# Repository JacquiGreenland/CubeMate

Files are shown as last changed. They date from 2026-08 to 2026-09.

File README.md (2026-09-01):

# CubeMateEQ

> **Compact open-source strain-wave drive telescope mount for luggable (portable) astrophotography and visual astronomy**

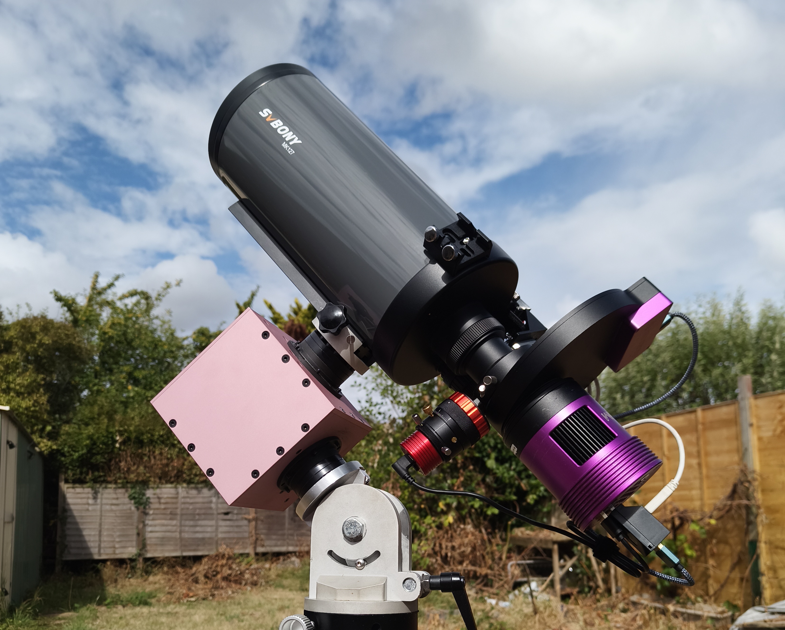
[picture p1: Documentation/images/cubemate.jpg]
CubeMateEQ


CubeMateEQ is a compact, open-source telescope mount designed around low-cost strain-wave (harmonic) gearboxes, stepper motors, CNC-machined aluminium parts, and the [OnStepX](https://github.com/hjd1964/OnStepX) control platform.

The project was created because I wanted to build my own mount based around strain-wave gearboxes and evolved into an exploration of how far a practical DIY strain-wave mount could be taken using off-the-shelf parts. The result is a vaguely travel-friendly, modular, and compact mount that can be assembled with basic tools. It can operate in either **Equatorial (EQ)** or **Alt-Az** configurations and has been validated with real astrophotography workloads, including guiding at approximately 1 metre focal length while carrying a 6 kg payload.

CubeMateEQ is intended as an **open hardware engineering project**, not a commercial product. It is buildable, modifiable, and intended to be improved by the community.

---

## Project status

CubeMateEQ is currently at a **field-validated prototype / open-hardware release** stage.

The current design has:

- been fully assembled in CNC-machined aluminium;
- been tested in both lightweight and higher-load configurations;
- demonstrated sustained guided astrophotography at approximately 975 mm focal length;
- demonstrated sub-arcsecond guiding for sustained periods;
- successfully produced long guided exposures (10 min) without meaningful exposure-time-dependent star elongation;
- been tested with OnStepX using an ESP32-S3-based controller on a custom PCB;
- been prepared for travel use as a practical hold-luggage astrophotography mount for heavier payloads.

The design is functionally complete, although there are still areas of refinement and experimentation, particularly around firmware behaviour, slew microstepping, mount limits, and future mechanical improvements.

---

## Why CubeMateEQ?

Commercial compact strain-wave drive mounts are excellent, but they were also extremely expensive when this project started. In recent years cheaper options using a similar mechanical principle to CubeMateEQ have appeared, but the major commercial brands still typically involve spending several times the parts cost of assembling CubeMateEQ.

CubeMateEQ was designed around my personal priorities:

- **open mechanical and electronic design;**
- **commodity strain-wave drives and motors;**
- **repairability and replaceable controller hardware;**
- **luggable form factor;**
- **real astrophotography performance rather than theoretical payload claims;**
- **modularity and scope for future upgrades.**

The aim is not to claim that CubeMateEQ is a drop-in replacement for every commercial strain-wave mount. Commercial products offer advantages such as factory QA, tested periodic-error characteristics, support, warranties, and polished integration.  Some manufacturers, such as MLAstro, offer similar repairability along with all the other commercial benefits of precision and support.

CubeMateEQ instead demonstrates what can be achieved with open hardware, relatively inexpensive components, careful mechanical design, and community software. It is not unique in this, but the design is highly modular and can be extended around the same basic form factor and principle.

---

## Why 'Luggable' and not 'Portable'

CubeMateEQ is notionally portable, and my wife and I certainly will be travelling with it, but it is not something you can simply throw into your hand luggage. It's the same size and weight as many commercial strain-wave mounts and it bothers me that they refer to them as portable!  The term is a deliberate nod to the old Compaq "luggables": portable PCs, certainly, but a long way from what laptops would eventually become.

---

## Why the name CubeMateEQ?

During development I used AI extensively to check calculations, analyse guiding logs, and accelerate a variety of supporting tasks so that I could spend more time on the engineering decisions themselves. At one point, somewhat randomly, the AI referred to the project as "CubeMateEQ". I liked the name enough that it stuck.

---

## Key features

- Compact CNC-machined aluminium construction
- Strain-wave drive RA and DEC axes
- Belt reduction between stepper motor and strain-wave gearbox
- Equatorial and Alt-Az operation
- Inexpensive ESP32-S3 controller
- OnStepX-compatible control electronics
- Open mechanical design
- Open PCB and wiring documentation
- Modular axis and mounting interfaces
- Designed for luggable astrophotography
- Proven with guided imaging at approximately 975 mm focal length
- Designed to be serviceable and reproducible using readily obtainable parts

---

## Mechanical architecture

The current CubeMateEQ prototype uses:

- **Type 14 cup-style strain-wave drives**
- **100:1 primary reduction**
- **NEMA 17 stepper motors**
- **GT2 belt reduction**
- **16-tooth motor pulley**
- **80-tooth driven pulley**
- **5:1 belt reduction**
- **500:1 total reduction**

The structure is CNC-machined aluminium and is designed around a compact cube-like form factor using a fully enclosed torsion-box structure for stiffness.

The current luggable configuration is intended for imaging payloads in the approximate **5–10 kg class**, with higher loads possible depending on balance, counterweight use, strain-wave drive selection, tripod/pier stiffness, and imaging requirements.

Larger strain-wave drives and stronger motors remain possible future development paths.

---

## Electronics and control

CubeMateEQ uses a custom controller PCB designed around a **Waveshare ESP32-S3 Zero** and TMC2209 stepper drivers.

The mount runs **OnStepX**, which provides:

- telescope mount control;
- sidereal tracking;
- GOTO operation;
- guiding support;
- EQ and Alt-Az mount modes;
- meridian and limit handling;
- INDI / application integration.

OnStepX needs to be downloaded separately and compiled with the supplied pinmap and configuration files along with any other desired software changes.

The repository includes CubeMateEQ-specific configuration material and the custom ESP32-S3 pin map required for the controller PCB.

> **Important:** always verify the supplied pin map against the PCB revision being built. Step/direction assignments and TMC UART addressing must agree with the physical board.

---

## Proven astrophotography performance

CubeMateEQ has been tested using several imaging configurations.  All of these tests were performed in suburban Bristol and not under pristine dark skies.

### ~180 mm imaging

With a lightweight imaging payload consisting of a ZWO ASI585MC Air and a Nikon 180 mm prime lens, using the custom wedge and an EQ5 tripod, CubeMateEQ has demonstrated sustained sub-arcsecond guiding.

### ~975 mm imaging

The mount was also tested with a substantially more demanding imaging train consisting of an SVBONY MK127 using its supplied focal reducer giving approximately **975 mm focal length** paired with an Altair filter wheel, an Altair 585MM camera, and a ZWO off-axis guider with a QHY5L-II-M guide camera, along with a stepper motor, bracket, and a DIY Moonlite-compatible focuser, in conjunction with the custom wedge and an EQ5 tripod.  This payload is approximately 6 kg in total - a 1.9 kg counterweight was used.

Representative results with this payload included:

- mature guiding around **1.2–1.4 arcsec RMS** near the celestial equator;
  - approximately **0.88 arcsec RMS** during a 240-second exposure;
  - approximately **1.15 arcsec RMS** during a 300-second exposure;

- sustained sub-arcsecond intervals imaging a more favourable high-declination target (C4);
  - approximately **0.59 arcsec RMS** during a 300-second exposure;
  - approximately **0.85 arcsec RMS** during a 600-second exposure.

Matched-star analysis showed no meaningful increase, or variation, in star elongation across exposure durations from 1 to 10 minutes.

These results are included as engineering validation rather than guaranteed performance. Guiding performance depends heavily on seeing, payload, balance, polar alignment, guiding configuration, optical geometry, tripod stiffness, wind, and individual strain-wave drive characteristics.

---

## Periodic error and guiding

As expected for an inexpensive commodity strain-wave gearbox, the RA axis exhibits periodic error.

Testing has shown a strong repeatable periodic component of approximately **428–431 seconds** in the Type 14 gearbox currently installed on the RA axis.

PHD2 Predictive PEC (PPEC) materially improves RA guiding once the period is learned.

Different gearboxes will almost certainly exhibit different periodic error. Because CubeMateEQ is designed around off-the-shelf components this variability is treated as something to accommodate through guiding rather than eliminate through individual selection of expensive high-precision components.

---

## Payload

CubeMateEQ does not use a single absolute payload rating because useful payload depends on the application, counterweights, distance of the payload from the centre of rotation, and many other factors.

As a practical guide:

- **5–6 kg without counterweight** is a realistic upper limit for luggable-use;
- around **10 kg** is a sensible design target for the current luggable configuration with appropriate counterweights;
- larger loads may be possible with a combination of counterweighting and careful setup;
- future Type 17 or larger strain-wave-drive variants could increase the available torque substantially.

For astrophotography, guiding performance is a more useful measure than whether the mount can simply carry a given mass.

---

## Counterweights

Like many strain-wave-drive mounts, CubeMateEQ can be used without a counterweight for lighter payloads.

Counterweights can still be useful because they:

- reduce static loading on the RA strain-wave drive;
- reduce tripod overturning moment;
- improve stability with longer or heavier optical systems;
- increase the usable payload range.

The current design supports counterweight use where required using a counterweight shaft with a 12 mm thread. This allows several different off-the-shelf counterweight systems to be used.  The reference model uses a ZWO counterweight shaft with a 12 mm thread and a 20 mm diameter and SkyWatcher EQ5 weights.

---

## Equatorial mounting

CubeMateEQ can be configured for equatorial use.

The current prototype uses a **custom EQ wedge**. That wedge is not included in the initial open release because the present design is functional but not sufficiently user-friendly to be recommended as a general solution.

Instead, the repository includes a step file for a Vixen-Style Dovetail plate that allows CubeMateEQ to be attached to other EQ wedge solutions.

A more refined open EQ wedge is planned for the future.

---

## Alt-Az operation

CubeMateEQ can also be operated as an Alt-Az mount through OnStepX.

This makes it suitable for:

- visual astronomy;
- planetary imaging;
- solar and lunar work;
- short-exposure imaging;
- applications where field rotation is acceptable or compensated elsewhere.

---

## Build cost

The current reference model was built for approximately **USD $500** although prices have risen a little since then and I would expect to pay around **USD $600** at current pricing.

This figure is indicative only and excludes:

- tripod / pier / wedge;
- variations in local pricing.
- shipping costs;
- import taxes;

At the time of writing the CNC aluminium parts and the PCB for the reference model cost approximately **USD $240**. The Type 14 strain-wave gearboxes can be sourced for as little as **USD $100 each** from Aliexpress. The stepper motors are sourced from StepperOnline for **USD $14 each**.  Ancillary parts, including the electronics, can be sourced from amazon for These two expenditures account for the bulk of the build cost, most of the rest of the items can be sourced from Amazon for about **USD $100** total.

Repeat builds may vary significantly depending on supplier and location. Supply chain status and availability of materials will also impact spot pricing.

---

## Repository contents

The repository is divided into the following functional directories:

```text
/
├── README.md
├── LICENSES.md
├── hardware/
│ ├── Mechanical/
│ └── PCB/
├── firmware/
│ ├── Config.h
│ ├── Extended.config.h
│ └── Pins.MaxESP4.h
└── Documentation/
```

The repository includes:

- mechanical STEP files;
- manufacturing drawings;
- PCB design files;
- controller pin mapping;
- CubeMateEQ-specific OnStepX configuration;
- Bill of Materials;
- assembly documentation.

---

## Assembly

Detailed assembly instructions are provided separately in the documentation.

The high-level build sequence is:

1. Assemble the strain-wave-drive axis structures.
2. Fit shafts, bearings, pulleys, and belts.
3. Install the stepper motors.
4. Assemble the RA and DEC structures.
5. Install the controller electronics.
6. Connect the stepper drivers and motors.
7. Attach the payload mounting interface.
8. Install the mount onto the chosen EQ wedge, pier, tripod, or Alt-Az base.
9. Flash and configure OnStepX.
10. Verify axis direction, travel limits, current settings, and motor mapping before mounting valuable equipment.

---

## Firmware

CubeMateEQ uses [OnStepX](https://github.com/hjd1964/OnStepX).

OnStepX is a separate project and remains subject to its own licence.

CubeMateEQ-specific configuration files are supplied only to make it easier to reproduce the tested hardware configuration.

Builders should retain a known-good firmware image before experimenting with settings such as:

- tracking microsteps;
- slew microsteps;
- motor current;
- Axis-1 limits;
- meridian behaviour;
- limit recovery;
- guide rate;
- mount startup behaviour.

---

## Safety

CubeMateEQ is an experimental open-hardware telescope mount.

A telescope mount is capable of producing substantial torque and can damage equipment, trap fingers, wrap cables, or drive an optical system into a tripod or pier if incorrectly configured.

Builders are responsible for validating:

- axis directions;
- software limits;
- physical clearances;
- cable routing;
- current limits;
- power supply;
- motor temperature;
- balance;
- mount stability.

Always test motion without valuable optics attached when commissioning a new build or firmware configuration.

---

## Licensing

CubeMateEQ uses separate licences for hardware and documentation.

### Hardware

Unless otherwise stated, CubeMateEQ hardware design files are licensed under:

**CERN Open Hardware Licence Version 2 — Strongly Reciprocal (CERN-OHL-S-2.0)**

This includes relevant:

- PCB design files;
- schematics;
- mechanical CAD;
- STEP files;
- manufacturing drawings;
- hardware assemblies.

### Documentation

Documentation is licensed under:

**Creative Commons Attribution-ShareAlike 4.0 International (CC BY-SA 4.0)**

### Software

CubeMateEQ does not redistribute OnStepX.

OnStepX and other third-party software remain under their respective licences.

### Name and branding

The **CubeMateEQ** name, logo, and project branding are not licensed under CERN-OHL-S-2.0 or CC BY-SA 4.0.

Use of the open hardware does not imply that a derived product is manufactured, certified, endorsed, or supported by the CubeMateEQ project.

See `LICENSES.md` for full details and the individual `LICENSE` file in each directory for the full text of the applicable licence.

---

## Contributing

Contributions, testing results, documentation improvements, and hardware refinements are welcome.

Particularly useful contributions include:

- build reports;
- alternative CNC / manufacturing approaches;
- verified component substitutions;
- guiding performance data;
- alternative EQ wedge designs;
- controller improvements;
- mechanical tolerance feedback;
- firmware configuration findings.

When submitting performance results, please include enough information to make the data useful, such as focal length, payload, guide configuration, exposure duration, seeing conditions where known, and firmware/configuration details.

---

## Project philosophy

CubeMateEQ exists because a telescope mount does not have to be a sealed proprietary appliance.

The project is intended to remain:

- understandable;
- repairable;
- reproducible;
- modifiable;
- experimentally useful.

Commercial manufacture, group buys, assembled boards, and paid build services are compatible with the project licence, provided the obligations of the CERN-OHL-S-2.0 licence are respected for covered hardware derivatives.

---

## Acknowledgements

CubeMateEQ would not exist without the work of the OnStep / OnStepX community and the wider open-source astronomy ecosystem.

Particular thanks go to the developers and contributors behind:

- [OnStepX](https://github.com/hjd1964/OnStepX)
- [PHD2](https://openphdguiding.org/)
- [INDI](https://indilib.org/)
- [KStars](https://kstars.kde.org/)

and to everyone who has documented, tested, and shared practical experience with DIY telescope mounts and harmonic-drive systems.

---

## Disclaimer

CubeMateEQ is provided as open hardware without warranty.

Build and use it at your own risk.

Astronomy equipment can be expensive. Verify every axis, limit, connector, voltage, current setting, and firmware configuration before connecting valuable equipment.

---

**CubeMateEQ — compact, open, repairable, and extendable hardware for astronomy.**

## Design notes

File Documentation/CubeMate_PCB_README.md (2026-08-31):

# CubeMate Controller PCB

## About this board

The CubeMate controller PCB is a custom two-axis controller designed specifically for CubeMate. It provides the electronics required to drive the right ascension (RA) and declination (DEC) axes using OnStepX, while keeping the controller simple, modular and easy to repair or replace.

The design is intentionally based around readily available modules rather than permanently soldered controller or driver ICs. In the reference build, the ESP32-S3 and both TMC2209 stepper drivers are socketed so that any of them can be replaced without removing the complete PCB from service.

The board can be assembled with surface-mount parts, but through-hole alternatives are provided for the resistor and capacitors so that a fully hand-soldered build is also possible. This guide assumes that the builder is already comfortable with basic electronic assembly, component polarity, continuity checking and soldering.

This document covers the controller PCB itself. Mechanical installation of the completed PCB into CubeMate is covered by the main CubeMate assembly guide.

## Main components

A complete controller uses:

| Component | Qty | Notes | Link| 
| --- | ---: | --- | --- |
| Waveshare ESP32-S3 Zero | 1 | Main OnStep controller. Some suppliers also describe this small-format board as an ESP32-S3 Mini. | https://www.aliexpress.com/item/1005009067129211.html |
| TMC2209 V3.0 stepper driver module | 2 | One driver for RA and one for DEC. Socketing is recommended. | https://www.aliexpress.com/item/1005010256315174.html |
| 100 uF, 35 V electrolytic capacitor | 2 | One on the motor-power supply line for each TMC2209. SMD footprint plus through-hole alternative pads are provided. |  |
| Mini 360 buck converter module | 1 | Regulates the incoming supply to 3.3 V for the ESP32-S3 and TMC2209 logic. | https://www.aliexpress.com/item/1005008498997638.html |
| 1 kohm resistor | 1 | Part of the shared single-wire TMC2209 UART interface. SMD footprint plus through-hole alternative pads are provided. | |
| JST-XH 4-pin board connector | 2 | One stepper-motor connector per axis. | |
| Status LED | 1 | OnStep status indication. Mounted on the underside of the PCB. | |
| 2 x 4 GPIO header | 1 | Exposes four otherwise-unused ESP32 GPIO connections for future expansion with individual ground pins. | |
| 5.5 x 2.1 mm horizontal PCB DC jack | 1 (optional) | Centre-positive in the reference build. Direct-wired power can be used instead. | |
| USB-to-TTL serial module | 1  | Reference build uses a ZY-CP2102 module. The PCB can also accommodate a CH340E-based module. | https://www.aliexpress.com/item/1005010271946733.html |
| Pin headers / sockets | As required | Used for replaceable modules and detachable panel wiring. | |

Exact supplier links can be added to this document where useful.

## Board orientation

Almost all components are fitted to the **top/component side of the PCB**, which is the side **without the CubeMate logo**. This includes:

- the ESP32-S3 Zero;
- both TMC2209 drivers;
- the Mini 360 buck converter;
- the two 100 uF capacitors;
- the 1 kohm UART resistor;
- the JST-XH motor connectors;
- the optional serial module;
- the power connector or power wiring;
- the expansion headers.

The **status LED is the exception**. It is mounted on the **underside/logo side** of the PCB.

When the completed board is installed in CubeMate, the populated side faces down into the enclosure and the underside faces the top cover. A small hole in the top cover allows the status LED to be seen without exposing the observer to a bright direct LED.

## Power input

The reference PCB can accept power through an optional horizontal **5.5 x 2.1 mm centre-positive DC barrel jack**. The same PCB pads may instead be used for directly soldered wires.

Using the barrel jack makes the internal power lead easy to disconnect when the PCB or top plate needs to be removed. A directly wired arrangement is equally valid and can use any suitable inline connector if removability is required.

The Mini 360 regulator itself accepts approximately **4.75 to 23 V DC**. The reference CubeMate build is operated from a **19 V** supply, using a repurposed laptop power supply fitted with a standard 5.5 x 2.1 mm plug. A good-quality **12 V** supply with sufficient current is also suitable. In practice, a stable supply in roughly the **15 to 19 V** range is a good choice for the reference system.

The power supply must also be appropriately rated for the two stepper motors and their TMC2209 drivers.

### Important: set the Mini 360 before installing the ESP32

> **Do not install or power the ESP32-S3 Zero or TMC2209 modules until the Mini 360 output has been adjusted and measured at 3.3 V.  Ideally set it on the bench before soldering to the board**

The Mini 360 is adjustable. Before fitting the ESP32-S3 Zero, power the board and use a multimeter to set and verify the regulator output at **3.3 V**.

Once the output has been confirmed, power the board off before installing the ESP32-S3.

## TMC2209 stepper drivers

CubeMate uses two **TMC2209 V3.0** modules, one for each axis.

### Socketing

Socketing the drivers is strongly recommended. The PCB can accept directly soldered modules, but sockets make a failed or damaged driver much easier to replace.  Standard pin header sockets are the simplest but I like the cut down the legs on the components and use IC sockets for a much lower profile.

The same approach is recommended for the ESP32-S3 Zero.

### Driver orientation

The TMC2209 modules have a required orientation. The orientation is not explicitly labelled on the silkscreen, but the footprint is visually keyed.

At one end of the TMC2209 module, the normal pin rail turns the corner and includes **two additional pins across the end of the module**. The corresponding pair of holes is present in the PCB footprint. Match this geometry before inserting the driver into its socket.

If a driver is soldered directly to the PCB, the complete footprint geometry makes the intended orientation apparent, but orientation should still be checked before soldering.

### Current / Vref adjustment

> **Do not assume that the default TMC2209 current setting is correct for your motors.**

Each TMC2209 must be adjusted for the stepper motor with which it is being used. Use the onboard potentiometer and the normal TMC2209 Vref/current-setting procedure for the particular driver module and motor.

There is no single correct setting for every CubeMate build because it depends on the motor specification.

I used the following link as a convenient calculator - https://grandpacad.com/en/tools/stepper-motor-vref-calculator

Incorrect driver adjustment can produce surprisingly erratic motor behaviour, so this should be treated as a normal part of commissioning the controller.

## TMC2209 UART interface

The two TMC2209 drivers use a **shared, addressable single-wire UART bus**. Both drivers connect to the same ESP32 UART/GPIO bus line and are distinguished by their configured TMC2209 addresses.

The PCB implements the normal one-wire TMC2209 UART arrangement, including the **1 kohm resistor in the ESP32 RX/TX UART path**.

Driver addressing and the corresponding GPIO assignment are defined by the OnStep configuration supplied with the CubeMate controller.

## Stepper motor connectors

Each axis uses a **4-pin JST-XH connector** wired directly to its TMC2209 motor outputs.

### Motor plug pin order

Viewing the **JST-XH plug from the top**, with the locating boss facing **downward**, the connection order from left to right is:

```text
2B   2A   1A   1B
```

On many common four-wire stepper motors this corresponds to:

```text
Black   Green   Blue   Red
```

Wire colours are **not universal**. Always confirm the two motor windings and the manufacturer's wiring information if the motor uses a different colour scheme.

## External serial interface

The ESP32-S3 Zero already has an onboard USB-C interface, and Wi-Fi control is also available through OnStep. However, the reference CubeMate design provides a separate USB-to-TTL interface for reliable wired serial control from a Raspberry Pi, PC or similar host.

This was added because the onboard ESP32-S3 Zero USB-C serial interface has not proved sufficiently reliable for routine serial use in the reference build.

The PCB is designed to accommodate two styles of serial module:

- a MSOP10 CH340E-based USB-to-TTL module with an onboard micro-USB connector; or
- the **ZY-CP2102 USB-TTL serial UART module** used in the reference CubeMate build.

The reference instructions below describe the ZY-CP2102 arrangement.

### TTL-side connections

CubeMate uses only:

```text
GND
TX
RX
```

on the TTL side of the serial module.

The module fits directly into the PCB position using 6 solder pads/through-holes, so the required TX/RX routing is already handled by the PCB layout. However the pinout of these 6 holes is indicated on the silkscreen.  

### ZY-CP2102 voltage-selector pads

The module is connected to the **centre 4 pins** as the outer pins provide additional power and ground lines for the MSOP10 module if it is used.

The reference ZY-CP2102 module has solder selectors for **5 V** and **3.3 V** operation.

For the CubeMate reference build, **both selector pads are left unbridged and cleaned of solder**.

The serial module is **not powered from the CubeMate controller PCB**. It becomes powered only when its USB side is connected to a host such as a PC or Raspberry Pi.

This arrangement avoids feeding host USB power into the main controller power system through the serial module.

### USB-side connections

The USB side of the CP2102 module presents:

```text
GND
D+
D-
VCC
```
and are labelled on the silkscreen.

These are connected to the panel-mounted USB fly lead according to the wiring of the particular panel connector or fly lead selected for the build.

Do not assume that every USB fly lead uses the same wire colours. Verify its pinout before soldering.

### Mounting the serial module

The CP2102 module can be mounted in either of two ways:

1. **Surface mounted** using the castellated edges of the module and the extended pads on the CubeMate PCB.
2. **Through-hole mounted** using pin headers or a similar removable connection.

The PCB also includes a second set of holes beside the CP2102 position. These holes are intentionally **not electrically connected**. They can be used to pass a pin header through the PCB and mechanically anchor the serial-module / USB-fly-lead connection.

In the reference build, this arrangement provides both mechanical support and a removable connector for the USB lead from the CubeMate top panel.

## Status LED

The LED is intended as the **OnStep status LED**.

Its GPIO assignment and behaviour are controlled by the supplied OnStep pin map and firmware configuration, rather than being fixed by this document. A builder modifying the firmware may therefore repurpose the LED if desired.

The LED is mounted on the underside/logo side of the PCB so that it faces the viewing hole in the CubeMate top cover when the PCB is installed.

## Expansion GPIO header

Four otherwise-unused ESP32 GPIO connections are exposed on a small header for future expansion.

They can potentially be used for features such as:

- switches or limit sensors;
- additional status indications;
- environmental sensors;
- other experimental or future CubeMate functions.

Check the supplied OnStep pin map and firmware configuration before assigning any of these pins to new hardware.

## Surface-mount and through-hole options

The reference PCB uses surface-mount versions of the capacitors and resistor, but matching **through-hole pads are also provided**.

This means the board does not require a hot-air station or hot plate to build. A builder who prefers conventional hand soldering can populate the alternative through-hole footprints instead.

The larger components - including the JST-XH connectors, sockets, headers, optional barrel jack and Mini 360 module - are conventional through-hole/module-mounted parts.

The serial module can likewise be surface mounted using its castellated pads or fitted using through-hole headers.

## Suggested assembly approach

There is no mandatory soldering sequence for the CubeMate PCB.

### If using surface-mount components

A convenient sequence is:

1. Populate and reflow the surface-mount components first.
2. Fit sockets for the ESP32-S3 and TMC2209 modules.
3. Fit the Mini 360 and any remaining module headers.
4. Fit the JST-XH connectors, power connector and other larger through-hole parts.
5. Fit the underside status LED.
6. Add the serial-module mounting and USB fly-lead connection in the preferred form.

This is only a practical sequence, not an electrical requirement.

### If using through-hole components

If the alternative through-hole capacitor and resistor pads are being used, the parts can simply be fitted in whatever order is most convenient. There is no particularly critical assembly sequence.

## Recommended commissioning checks

Before installing the controller in CubeMate:

1. Inspect the PCB carefully for solder bridges, poor joints and incorrect component orientation.
2. Check continuity and verify that the power rails are not shorted.
3. Leave the ESP32-S3 Zero out of its socket.
4. Apply power and adjust the Mini 360 output to **3.3 V**.
5. Power off and install the ESP32-S3 Zero.
6. Confirm that both TMC2209 modules are installed in the correct orientation.
7. Set each TMC2209 Vref/current limit for its particular stepper motor using the normal TMC2209 procedure.
8. Confirm the JST-XH motor wiring before connecting the steppers.
9. If using the reference ZY-CP2102 module, confirm that the 5 V and 3.3 V selector pads are both unbridged.
10. Verify the USB fly-lead pinout before connecting it to the CP2102 module.
11. Load/configure OnStep using the supplied CubeMate pin map and settings.
12. Test both axes at low speed before carrying out normal slews.

## Replaceability and serviceability

One of the main design goals of the CubeMate PCB is that the controller should remain easy to repair and upgrade.

Where practical, the reference build therefore uses:

- socketed TMC2209 drivers;
- a socketed ESP32-S3 Zero;
- removable JST-XH motor connectors;
- a detachable power connection;
- a detachable USB fly lead;
- a modular USB-to-TTL interface.

This allows most likely points of failure - or future upgraded controller modules - to be replaced without rebuilding the complete electronics assembly.

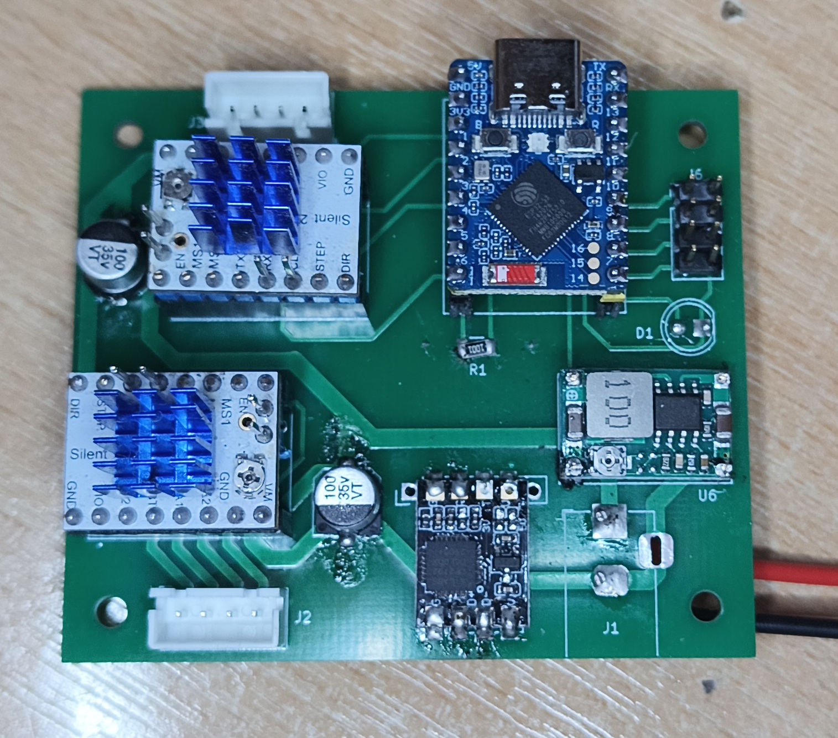
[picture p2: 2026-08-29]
Documentation/images/Cubemate PCB Front.jpg

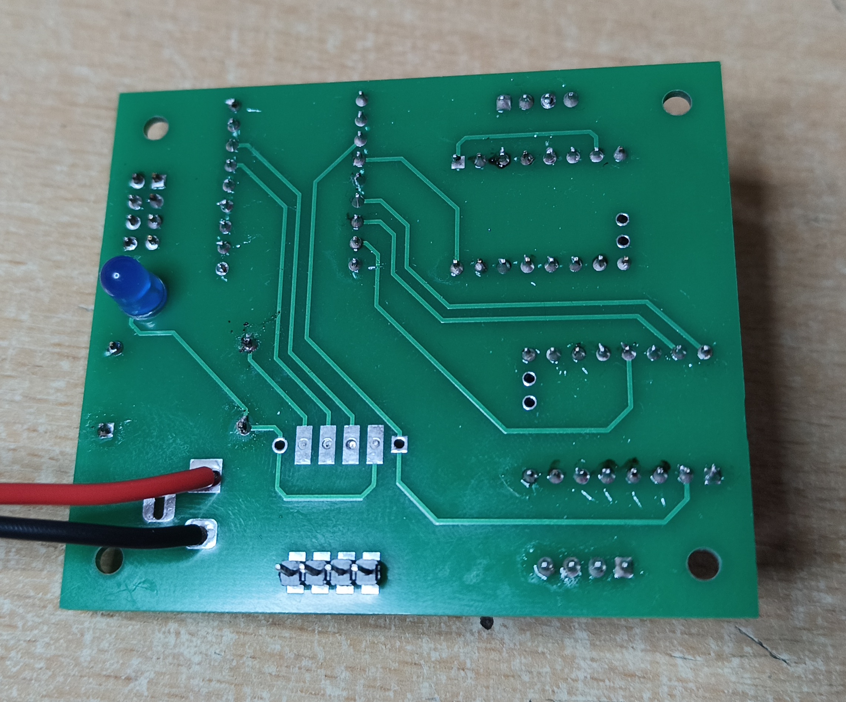
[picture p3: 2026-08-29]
Documentation/images/Cubemate PCB Rear.jpg

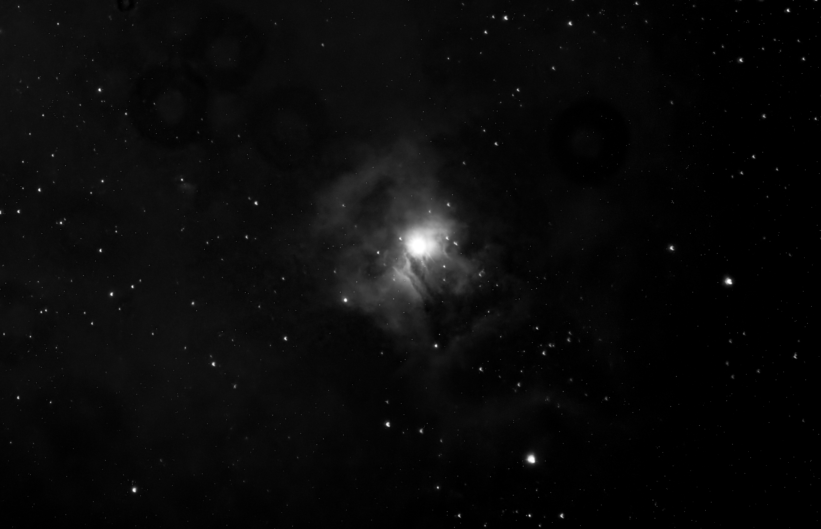
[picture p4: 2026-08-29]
Documentation/images/Cubemate-600-seconds-975mm.png

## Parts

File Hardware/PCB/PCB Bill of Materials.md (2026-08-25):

1 x ESP32 S3 Zero/Mini

2 x TMC2209 Stepper Motor Driver

1 x Mini360 Buck Converter

2 x SMD Electrolytic Capacitor 6.3 x 5.9 100uF

2 x JST_XH_B4B-XH-A_1x04 Connector

1 x 1206 SMD Resistor 100 Ohms1 x through hole LED (your choice of colour)

1 x ZY_CP2102 TTL to USB 2.0 module (board also accepts CH340E MSOP10 module)

1 x 5.5mm x 2.1mm DC barrel jack (either solder to board or solder external wires)

2.54mm Pin Headers and PCB sockets to suit

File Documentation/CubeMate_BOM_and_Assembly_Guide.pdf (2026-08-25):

CubeMate Mechanical Assembly Guide

# CubeMate

## Bill of Materials and Mechanical Assembly Guide

Scope: This document covers the mechanical assembly of CubeMate, installation of the already-built controller PCB onto the top plate, and the published payload / EQ-wedge interface plates. Construction and wiring details for the custom controller PCB are intentionally outside this guide and will be documented separately.

# Contents

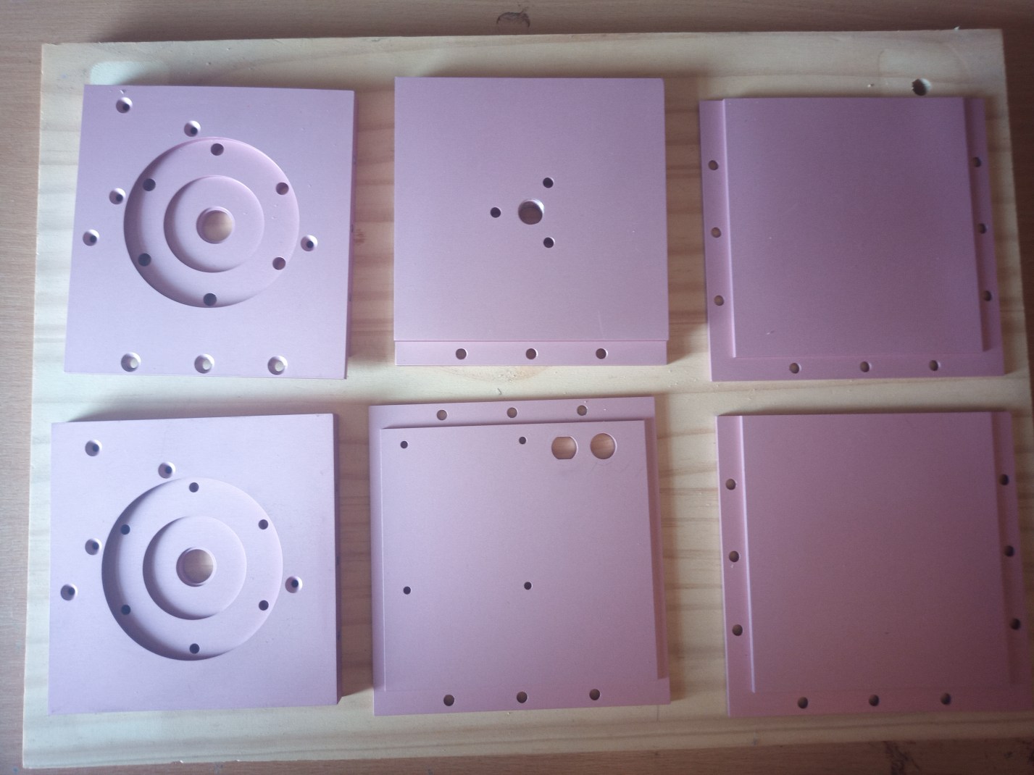
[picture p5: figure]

# Bill of Materials

Quantities below are for one complete two-axis CubeMate using the demonstrated 80T : 16T, 5:1 belt reduction on both RA and DEC. Alternative main-pulley sizes are listed separately and are substitutions, not additional parts.

Category | Item | Qty | Specification / notes
Machined structure | RA base / RA drive plate | 1 | Primary bottom plate; machined harmonic-drive seat and bearing location; no rebated edge lip.
Machined structure | DEC drive plate | 1 | Axis plate; mechanically the same drive assembly as RA, but with a rebated locating lip for positive engagement with the RA base plate.
Machined structure | Rear / counterweight plate | 1 | Outer plate with counterweight mounting point and rebated locating lip.
Machined structure | Left side plate | 1 | Machined side plate with rebated locating geometry; current STEP file engraved LEFT.
Machined structure | Right side plate | 1 | Machined side plate with rebated locating geometry; current STEP file engraved RIGHT.
Machined structure | Top plate | 1 | Rebated top closure plate, machined for the controller PCB, power connector and USB-C connector.
Machined structure | Motor mounting plate | 2 | Identical RA and DEC internal motor plates; each accepts one 5 mm bearing and five standoffs.
Drive train | Type 14 cup-style harmonic drive, type ZXS14 for 42mm Stepper | 2 | https://www.aliexpress.com/item/1005006190112225.html
Drive train | 5 mm drive shaft | 2 | 50–60 mm long, cut to suit. 60 mm works mechanically but protrudes farther than necessary.
Drive train | NEMA 17 stepper motor - 17HM15-0904S 0.9 Degree 36Ncm | 2 | https://www.stepperonline.co.uk/nema-17-bipolar-0-9deg-36ncm-51oz-in-0-9a-42x42x40mm-4-wires-17hm15-0904s.html (https://www.stepperonline.co.uk/nema-17-bipolar-0-9deg-36ncm-51oz-in-0-9a-42x42x40mm-4-wires-17hm15-0904s.html)
Drive train | GT2 16-tooth motor pinion | 2 | 5 mm bore.
Drive train | GT2 80-tooth main pulley / gear | 2 | 5 mm bore. Demonstrated configuration; gives 5:1 reduction with 16T motor pinion.
Drive train | GT2 60-tooth main pulley / gear | Optional substitute | 5 mm bore; gives 3.75:1 reduction with 16T pinion. Easier belt-tension access than 80T. The lower reduction slightly reduces theoretical drive resolution, but this was not considered materially significant for the intended system.
Drive train | GT2 48-tooth main pulley / gear | Optional substitute | 5 mm bore; gives 3:1 reduction with 16T pinion. Easier belt-tension access than 80T. The lower reduction slightly reduces theoretical drive resolution, but this was not considered materially significant for the intended system.
Drive train | GT2 drive belt, 200 mm | 2 | Specified for the demonstrated 80T/16T arrangement.
Bearings / spacers | Flanged bearing | 4 | 5 mm ID × 14 mm OD × 5 mm depth, with 1 mm locating flange. Two per axis.
Bearings / spacers | Nylon pulley spacer washer | 10 | 5 mm ID × 1 mm thick. Five per axis; distribute above/below the main pulley as required for pulley alignment.

Category | Item | Qty | Specification / notes
Standoffs | Motor-plate standoff | 10 | M3 female–female × 24 mm. Steel preferred over brass for rigidity; five per axis.
Standoffs | Controller-PCB standoff | 4 | M3 female–female, 10–24 mm acceptable; 24 mm used in the demonstrated build.
Fasteners | M4 × 20 mm button-head machine screw | 12 | Six per harmonic drive, through RA/DEC plate into the harmonic-drive threaded holes.
Fasteners | M3 × 10 mm button-head machine screw | 10 | Five per axis; secures motor-plate standoffs to the motor mounting plate.
Fasteners | M3 × 16 mm countersunk machine screw | 10 | Five per axis; secures each motor mounting plate/standoff assembly to its RA or DEC plate.
Fasteners | M3 × 12 mm button-head machine screw | 8 | Four per motor; screws through the motor plate into the NEMA 17 motor.
Fasteners | M3 nut used as rigid spacer | 8 | Four per motor. Used loose as a spacer, not as a conventional nut; optional if the standoff mounting holes are countersunk.
Fasteners | M3 washer used with motor spacer | 8 | Four per motor; paired with spacer nuts in the demonstrated build.
Fasteners | M4 × 16 mm countersunk machine screw | 18 | 3 DEC-to-RA + 3 rear-to-RA + 6 telescope dovetail + 6 chosen RA-to-wedge interface plate.
Fasteners | M4 × 12 mm countersunk machine screw | 24 | 18 for the two side plates (9 each) + 6 for the top plate.
Fasteners | M3 × 8 mm countersunk machine screw | 4 | Secures controller-PCB standoffs to the top plate.
Fasteners | M3 × 8 mm button-head machine screw | 4 | Secures the controller PCB to its four standoffs.
Electronics / interfaces | Custom CubeMate controller PCB | 1 | Preassembled controller PCB with ESP32-S3; electronics construction documented separately.
Electronics / interfaces | Panel-mount power connector | 1 | 5.5mm x 2.1mm DC Jack, to pass through 11mm mounting hole https://www.amazon.co.uk/RUNCCI-YUN-Pigtail-Connector-connectors-connector/dp/B0CX4T74SR/ (https://www.amazon.co.uk/RUNCCI-YUN-Pigtail-Connector-connectors-connector/dp/B0CX4T74SR/)
Electronics / interfaces | Panel-mount USB-C connector | 1 | 4 wire USB-C data cable, to pass through 11mm hole with flattened top and bottom. https://www.amazon.co.uk/dp/B0CPLRH4W6
Electronics / interfaces | Removable wiring headers / connectors | As required | Builder’s choice. Demonstrated build uses plug-in headers so panel connectors can be disconnected.
Payload interface | Vixen-style telescope dovetail mount | 1 | STEP file supplied; attaches to DEC axis with six M4 × 16 countersunk screws.
EQ-wedge interface | Vixen dovetail plate OR Losmandy plate | 1 | Choose one published STEP interface for the RA axis, or use a custom application-specific plate. Six M4 × 16 countersunk screws.

Category | Item | Qty | Specification / notes
EQ-wedge interface | EQ wedge | 1 | User-selected. The prototype custom CubeMate wedge is intentionally not part of the published design at present.

## Tools and consumables

- Hex keys / drivers for the selected M3 and M4 socket-head fasteners. The demonstrated build uses hexdrive hardware throughout.
- G-clamp, vice or other controlled press for bearing insertion. A tube and hammer can be used, but carries a greater risk of bearing damage.
- Soft protective layer between tools/clamps and anodised parts to avoid marking the finish.
- Engineer’s square or equivalent squaring tool for final frame alignment.
- Small flat spanner (useful if the M3 spacer nuts bind while tightening the motor).
- Grease supplied with the harmonic drive, or a suitable alternative.
- Thread-locking compound is optional; it has not proved necessary in the demonstrated build.
- Optional drill/countersink tools if modifying the motor plates or drilling the threads out of spacer nuts.

# Assembly Instructions

General fastening note: Unless a step explicitly says otherwise, leave the outer structural plate fasteners only snug during initial fit-up. Final tightening is performed in a controlled squaring sequence. Tighten firmly, but do not over-torque the aluminium threads or countersunk joints.

Finish protection: Use a soft protective layer wherever clamps, vices or other tools contact the anodised aluminium. The prototype used tissue paper; any clean, non-abrasive protective layer is suitable.

## 1. Assemble the RA drive module

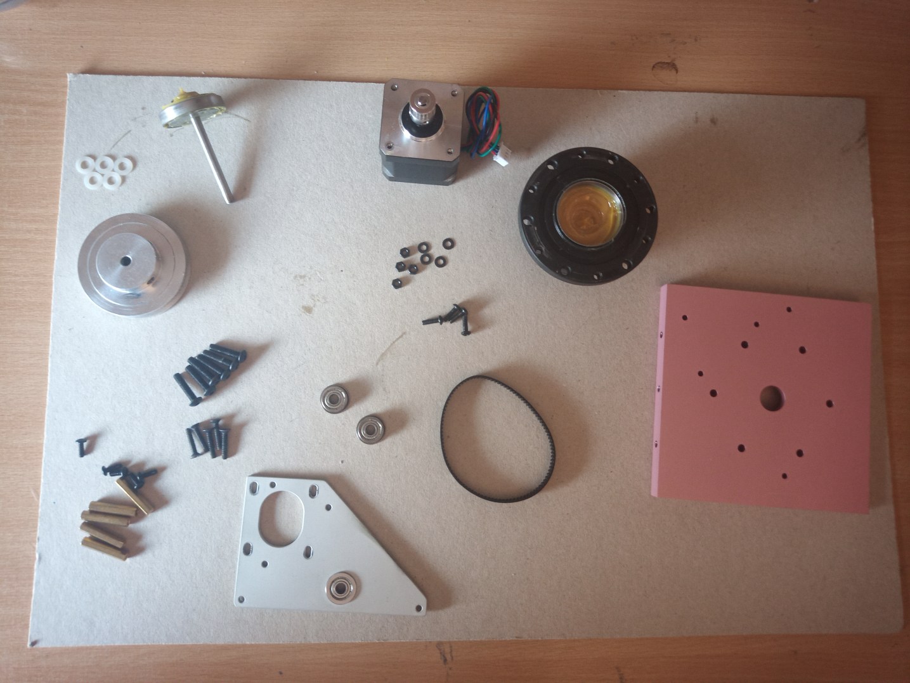
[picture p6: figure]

### 1.1 Press in the RA-base and motor-plate bearings

1. Press the first 5 × 14 × 5 mm flanged bearing into the central bearing seat in the RA base plate. The machining determines the correct insertion direction: press it fully into the recess so the locating flange sits flush with the machined surface.
2. Press the second bearing into the central hole of the motor mounting plate. Its orientation is not functionally important; the flange will rest against one face and the bearing will project approximately 1 mm through the opposite face.
3. Use a G-clamp, vice or other controlled pressing method where possible. A hammer and suitable tube can work, but is more likely to damage the bearing.

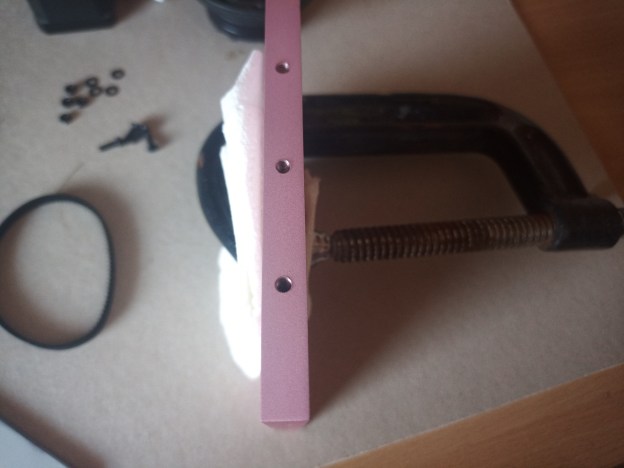
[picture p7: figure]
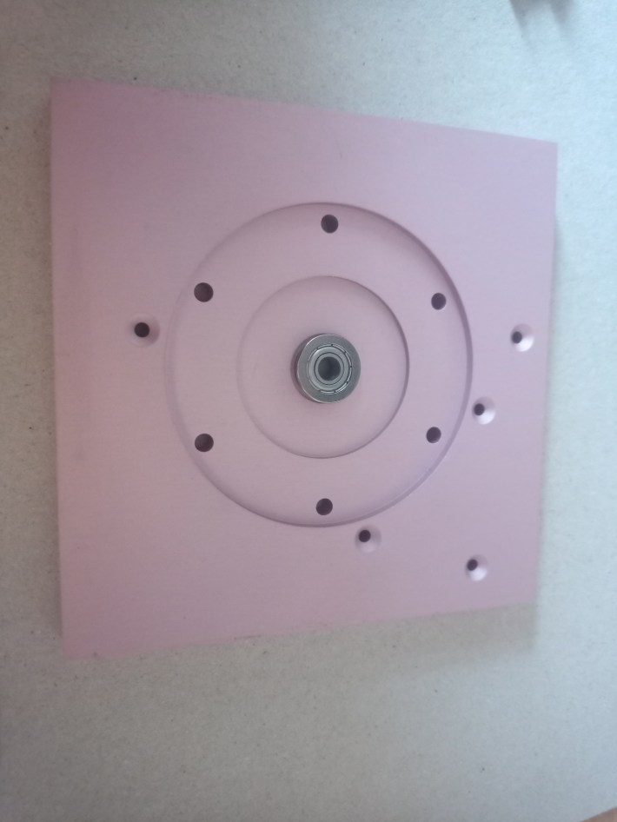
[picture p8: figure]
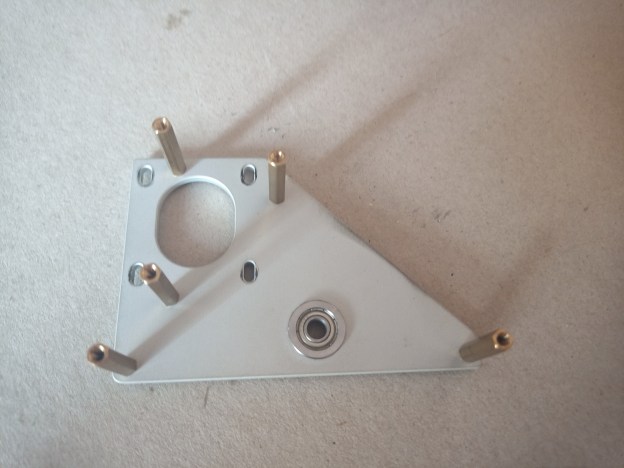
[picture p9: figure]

### 1.2 Fit the harmonic-drive wave generator and cup

4. Secure the harmonic-drive wave generator to the 5 mm drive shaft using the wave generator’s own grub/set screws.
5. Ensure the inside of the harmonic-drive cup is well greased. Use the grease supplied with the drive, or a suitable alternative. The drive design permits later greasing from outside, but doing it now is easier.
6. Place the cup-style Type 14 harmonic drive into its machined seat in the RA base plate and feed the 5 mm shaft through the bearing.
7. From the shaft side of the RA plate, install six M4 × 20 mm button-head machine screws into the threaded harmonic-drive holes. Tighten evenly to clamp the drive into its seat. Button heads are preferred for clearance.

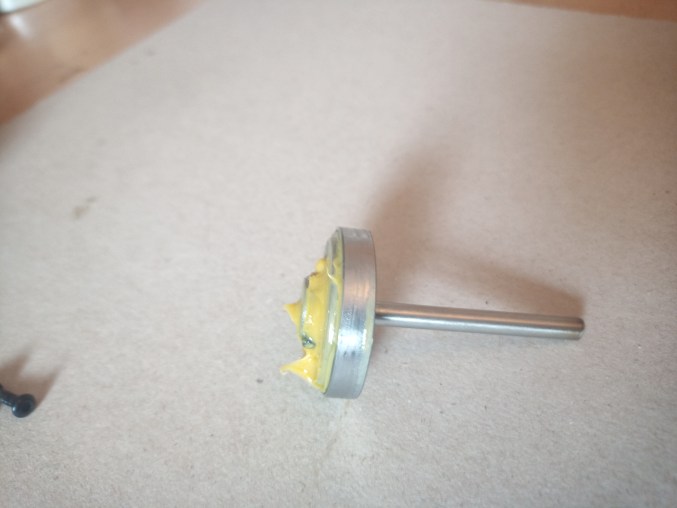
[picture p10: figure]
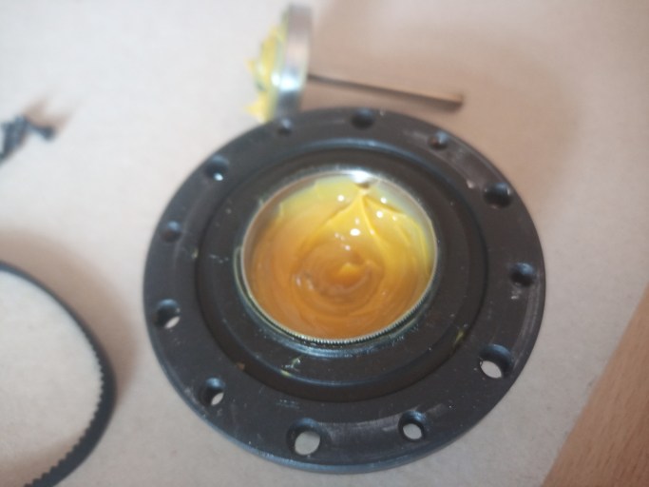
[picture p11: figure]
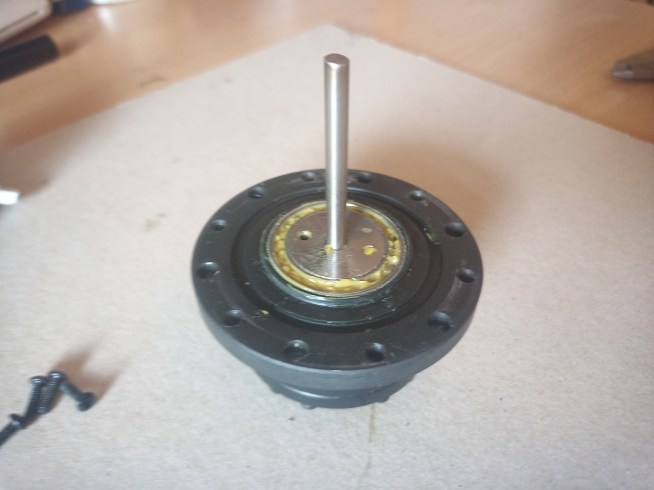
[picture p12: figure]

### 1.3 Fit the motor-plate standoffs

8. Orient the motor mounting plate as shown in the build photographs. The plate only fits the completed RA assembly in one geometry, but the early plates are not direction-marked.
9. Attach five M3 female–female × 24 mm standoffs to the motor mounting plate using five M3 × 10 mm button-head screws. All five standoffs project from the same face shown in the photographs.
10. Tighten the standoff screws firmly. Thread-locking compound may be used, but is optional.


### 1.4 Mount the NEMA 17 motor

11. The NEMA 17 mounts on the face of the motor plate opposite the five standoffs.
12. For the demonstrated non-countersunk motor plate, insert four M3 × 12 mm button-head screws through the slotted motor holes. On the motor side of the plate, place one M3 washer and one M3 nut over each screw as a rigid spacer.
13. The M3 nuts are spacers only: do not tighten them as conventional nuts. The screws continue through the spacers and tighten directly into the threaded NEMA 17 motor face.
14. Do not fully tighten the motor yet. Leave enough freedom for the motor to slide laterally in the slotted holes so that the GT2 belt can be tensioned.
15. If a spacer nut binds while tightening, a thin flat spanner can be used to free it. An optional modification is to drill the M3 thread out of the spacer nuts so they behave as plain bushes.
16. Alternative: countersink the five standoff mounting holes in the motor plate so their screw heads sit flush. If this is done, the motor can mount directly to the plate and the M3 nut/washer spacers are unnecessary.


### 1.5 Initial main-pulley positioning

17. Place a 5 mm ID × 1 mm nylon spacer washer on the RA shaft above the RA-plate bearing as an initial spacing reference.
18. Slide the 80T main pulley onto the 5 mm shaft with its hub/grub-screw side closest to the RA plate and the broad gear face farther away from the RA plate.
19. Do not tighten the 80T pulley grub screws yet. Pulley alignment is established first.
20. The final spacer distribution depends on the axial position of the 16T motor pinion. The aim is simply to align the 16T and 80T pulley tooth planes.

### 1.6 Test-fit the motor plate and set belt tension

21. Loop the 200 mm GT2 belt around the 16T motor pinion and the 80T main pulley.
22. Slide the motor-plate assembly down over the 5 mm shaft so that its bearing engages the shaft, then align the five standoffs with their mounting holes in the RA plate.
23. Temporarily secure at least three standoffs with M3 × 16 mm countersunk screws. Use three points spread around the pattern to triangulate the assembly. Tighten only snugly: the purpose is to hold the motor plate rigidly while belt tension is set.
24. Slide the motor across its slotted mounting holes until the GT2 belt has sensible working tension. Do not over-tension the belt; it only needs positive tooth engagement without excessive preload.
25. Tighten the motor mounting screws that are accessible. With the demonstrated 80T main pulley, only three of the four screws can be reached while assembled. With a 60T or 48T pulley, all four can be tightened in situ and the removal/reassembly steps below are unnecessary.


1.7 80T-only: remove the motor assembly and lock the motor position
26. Remove the three temporary M3 × 16 mm motor-plate fixing screws.
27. Slide the motor-plate assembly back off the 5 mm shaft. The tensioned belt prevents clean removal while the 80T pulley remains on the shaft, so allow the 80T pulley to slide off the shaft with the belt still looped around it.
28. Once clear of the RA shaft, remove the 80T pulley and belt from the motor assembly as needed for access.
29. Tighten the previously inaccessible fourth motor mounting screw, then snug all four motor screws firmly. The motor position now preserves the belt tension established during the test fit.

### 1.8 Final 80T pulley and belt installation

Spacer stack: Use five 1 mm nylon spacer washers per axis in total. Their split above and below the 80T pulley depends on the axial position of the 16T motor pinion. The prototype uses one below and four above; another build might use two below and three above. The objective is pulley alignment and prevention of unwanted axial movement.

30. Place the required lower nylon spacer washer(s) on the installed 5 mm RA shaft, then slide the 80T pulley onto the shaft. Keep the pulley grub screws loose.
31. Fit the remaining nylon spacer washers above the 80T pulley so the total spacer count for the axis is five.
32. Preferred 80T method: loop the belt around the 16T motor pinion first. Bring the motor assembly into position, place the belt over the RA shaft and engage the belt over part of the 80T pulley circumference.
33. Rotate the 80T pulley to “walk” the belt over the remaining teeth. The belt has just enough compliance to snap into full engagement without dismantling the motor mounting.
34. Move the motor-plate assembly into line with the RA shaft, ensure the upper bearing is accurately aligned, then slide the complete assembly down onto the shaft and standoffs.
35. Alternative method: preassemble the pulley/belt/spacer relationship on a spare piece of 5 mm shaft, align it precisely with the installed shaft, and slide the assembly into place. Take care to keep both shafts perfectly aligned.
36. Install all five M3 × 16 mm countersunk motor-plate screws and tighten them fully.
37. Verify that the two pulleys are axially aligned, the GT2 belt is correctly seated, and the belt tension remains appropriate. Only then tighten the 80T pulley’s own grub/set screws onto the 5 mm drive shaft.

## 2. Assemble the DEC drive module

Repeat Section 1 in full for the DEC plate. The DEC drive assembly is a complete duplicate of the RA drive assembly: same Type 14 harmonic drive, shaft, bearings, motor mounting plate, NEMA 17 motor, pulleys, belt, standoffs, spacers and fasteners. The only functional plate difference is the DEC plate’s rebated edge lip, which positively locates it onto the RA base plate during cube assembly.

## 3. Assemble and square the CubeMate outer structure

### 3.1 Join the DEC plate to the RA base plate

38. Place the completed RA base plate on the work surface as the bottom of the cube.
39. Engage the DEC plate’s rebated locating lip with the matching edge of the RA plate. The geometry only fits correctly in one location. As an orientation reference, when looking down on the RA plate with the RA stepper motor in the top-left corner, the DEC plate attaches to the edge opposite the RA motor.
40. Install three M4 × 16 mm countersunk screws through the DEC plate into the RA plate. At this stage, tighten them only snugly.


### 3.2 Fit the rear / counterweight plate

41. Fit the rear/counterweight plate to the RA base plate on the edge opposite the DEC plate. Its rebated lip and mounting pattern permit only the correct orientation.
42. Install three M4 × 16 mm countersunk screws. Leave them snug rather than fully tightened.

### 3.3 Fit the left and right side plates

43. Fit the left and right side plates into their rebated locating slots. Current STEP files have LEFT and RIGHT engraved into the parts; early prototype plates are unmarked, but the hole patterns only register in the correct orientation.
44. Install nine M4 × 12 mm countersunk screws per side plate (18 total). Keep all side-plate screws snug at this stage so the structure can settle square before final tightening.


### 3.4 Square and fully tighten the structure

45. Use an engineer’s square or equivalent tool to bring the frame as accurately square as possible. Pay particular attention to the RA-to-DEC plate angle. With accurate machining, the rebated joints should naturally pull into square as the fasteners are tightened.
46. First square the DEC plate to the RA base plate. Fully tighten the three DEC-to-RA M4 × 16 countersunk screws, taking care not to over-torque them.
47. With the DEC/RA angle held square, fully tighten the side-plate screws that attach the side plates to the DEC plate.
48. Next square the rear/counterweight plate. Fully tighten its three M4 × 16 countersunk screws into the RA plate.
49. Fully tighten the side-plate screws that attach the side plates to the rear/counterweight plate.
50. Finally, fully tighten the side-plate screws that attach both side plates to the RA base plate. The main mechanical cube structure is now rigidly assembled.

## 4. Assemble and install the top plate

### 4.1 Mount the controller PCB

51. Attach four M3 female–female standoffs to the top plate using four M3 × 8 mm countersunk screws. The demonstrated build uses 24 mm standoffs; any length from 10 mm to 24 mm is acceptable. Avoid exceeding 24 mm because internal space becomes limited.
52. Orient the controller PCB so that its underside faces the top plate and the populated/component side faces down into the cube. The power and USB headers should face into the available open internal space, and the ESP32-S3 should sit approximately in the corner of the top plate as shown in the reference photograph.
53. Secure the PCB to the four standoffs using four M3 × 8 mm button-head screws.


### 4.2 Fit the power and USB-C panel connectors

54. Fit the chosen panel-mount power connector into its dedicated top-plate opening. [LINK REQUIRED: exact connector used]
55. Fit the chosen panel-mount USB-C connector into the second dedicated top-plate opening. [LINK REQUIRED: exact connector used]
56. Wire both connectors to the controller PCB using the connection method of your choice. The demonstrated build uses removable plug-in headers so the top plate can be disconnected easily.

### 4.3 Connect the motors and close the cube

57. Connect the RA and DEC stepper motors to the controller PCB in accordance with the separate electronics/controller-board instructions.
58. Lower the top plate into place with the panel-mount power and USB-C connectors facing the rear/counterweight side of the CubeMate. This orientation allows the PCB to descend into the available internal space.
59. Seat the top plate fully into its machined rebate.
60. Install six M4 × 12 mm countersunk screws: three into the rear/counterweight plate and three into the DEC plate. Tighten all six fully.


## 5. Fit the telescope and EQ-wedge interfaces

### 5.1 DEC telescope dovetail mount

61. Fit the supplied Vixen-style telescope dovetail mount to the DEC axis. A STEP file for this component is included with the project.
62. Secure the dovetail mount using six M4 × 16 mm countersunk screws.

### 5.2 RA-to-EQ-wedge interface

63. The prototype uses a custom-designed EQ wedge and custom RA interface. That wedge is not currently intended for publication because it is not sufficiently user-friendly.
64. For a published build, choose either the supplied Vixen-dovetail STEP interface or the supplied Losmandyplate STEP interface, according to the EQ wedge being used. A builder may alternatively design an application-specific RA interface.
65. Secure the chosen RA interface plate using six M4 × 16 mm countersunk screws.
66. Attach CubeMate to the selected EQ wedge using the chosen Vixen, Losmandy or custom interface mechanism.


## 6. Final mechanical checks

- All outer plates are seated fully in their machined rebates/lips and the cube remains square.
- All structural M4 fasteners are fully tightened without over-torquing.
- Both harmonic drives are correctly seated and lubricated.
- Both 80T main pulleys are secured to their 5 mm shafts with their grub/set screws.
- RA and DEC pulley pairs are axially aligned and both GT2 belts have moderate, not excessive, tension.
- Both motor mounting plates are fully secured at all five M3 × 16 points.
- Motor wiring clears both drive assemblies and cannot foul the belts or pulleys.
- Top-plate PCB and panel connectors clear the internal mechanisms.
- DEC payload dovetail and RA wedge-interface plate are securely attached.

Assembly complete: At this point the CubeMate mechanical assembly is complete. Controller configuration, firmware setup, motor-driver settings, commissioning, polar alignment and the separate EQ-wedge build are outside the scope of this mechanical guide.

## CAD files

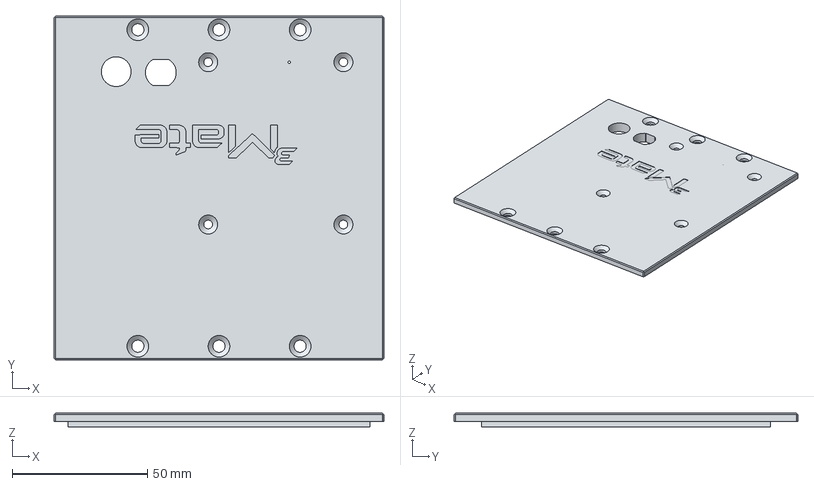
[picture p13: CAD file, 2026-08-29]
Hardware/Mechanical/Cubemate-Top Plate.step
122.0 x 127.0 x 5.00 mm

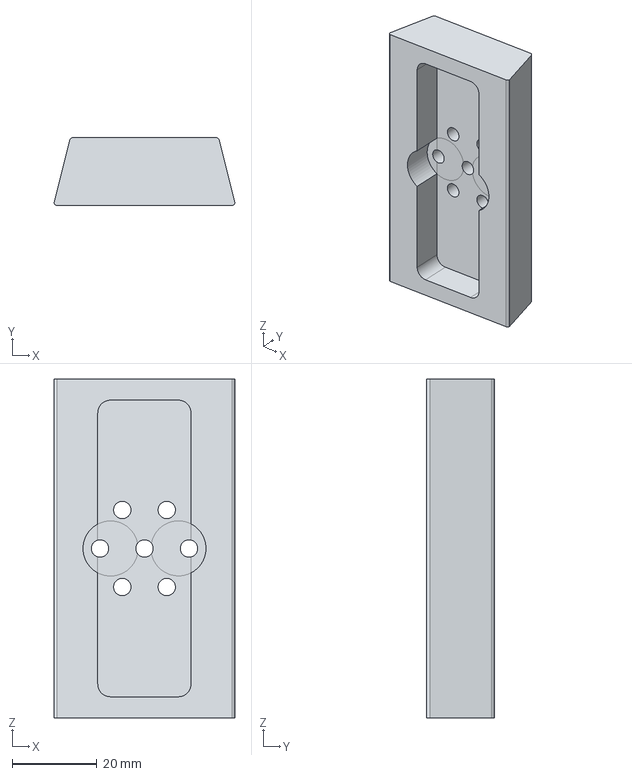
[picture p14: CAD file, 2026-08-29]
Hardware/Mechanical/Cubemate-Vixen Baseplate.step
42.6 x 16.0 x 80.0 mm

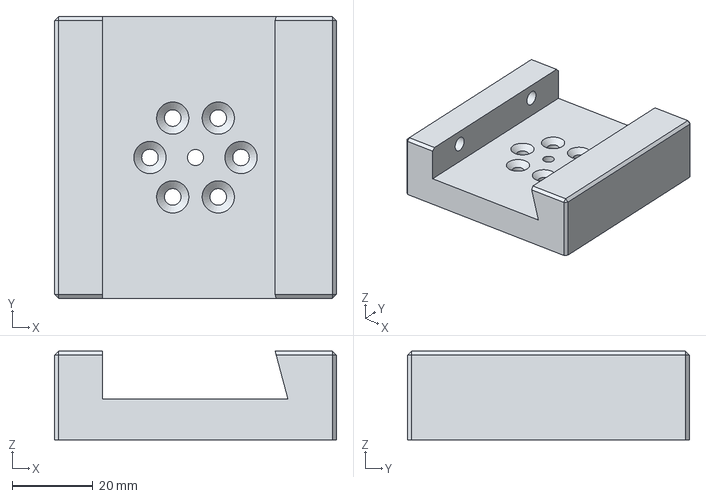
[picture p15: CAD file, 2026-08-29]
Hardware/Mechanical/Cubemate-Vixen Saddle.step
70.0 x 70.0 x 22.0 mm

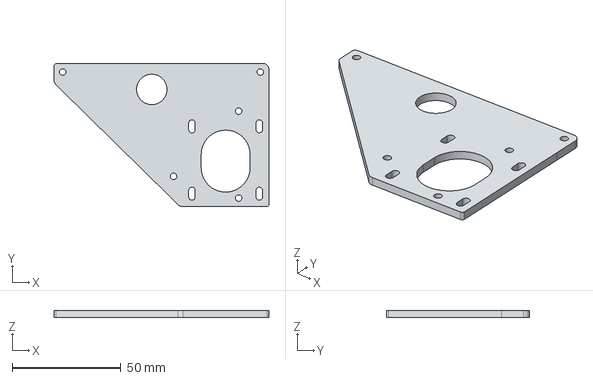
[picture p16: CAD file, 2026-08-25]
Hardware/Mechanical/Cubemate-DEC Motor Bracket.step
99.0 x 66.0 x 3.00 mm

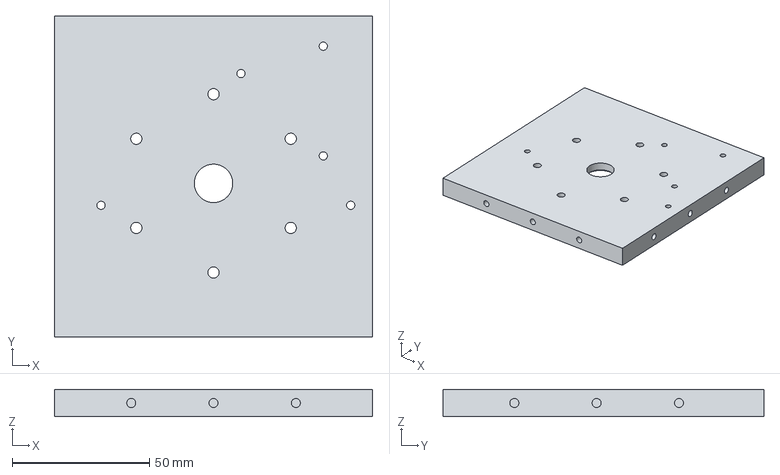
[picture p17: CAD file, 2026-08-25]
Hardware/Mechanical/Cubemate-RA Drive Plate.step
116.0 x 117.0 x 10.0 mm

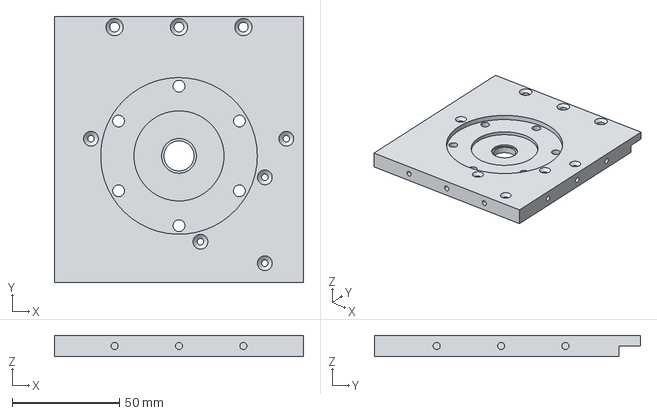
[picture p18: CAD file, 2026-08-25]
Hardware/Mechanical/Cubemate-DEC Drive Plate.step
116.0 x 124.0 x 10.0 mm

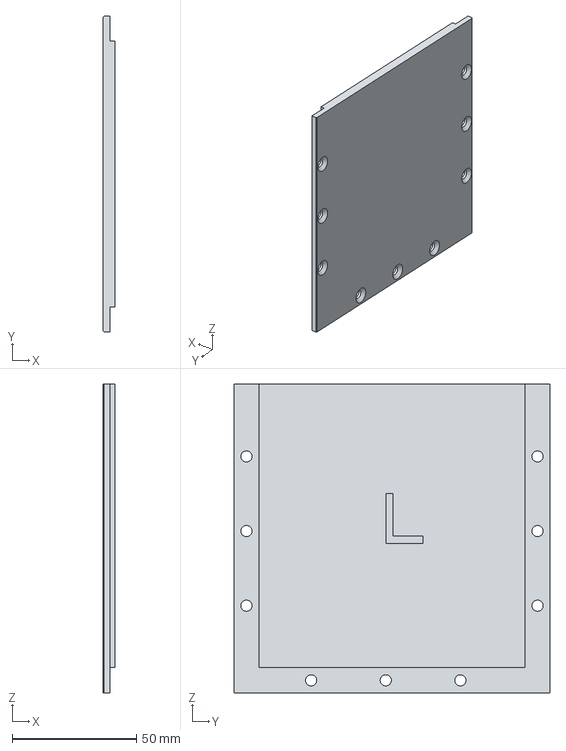
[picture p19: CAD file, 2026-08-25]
Hardware/Mechanical/Cubemate-Side plate 2.step
5.00 x 127.0 x 124.0 mm

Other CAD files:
Hardware/Mechanical/Cubemate-Side Plate 1.step
Hardware/Mechanical/Cubemate-CW Plate.step
Hardware/Mechanical/Cubemate-RA Motor Bracket.step

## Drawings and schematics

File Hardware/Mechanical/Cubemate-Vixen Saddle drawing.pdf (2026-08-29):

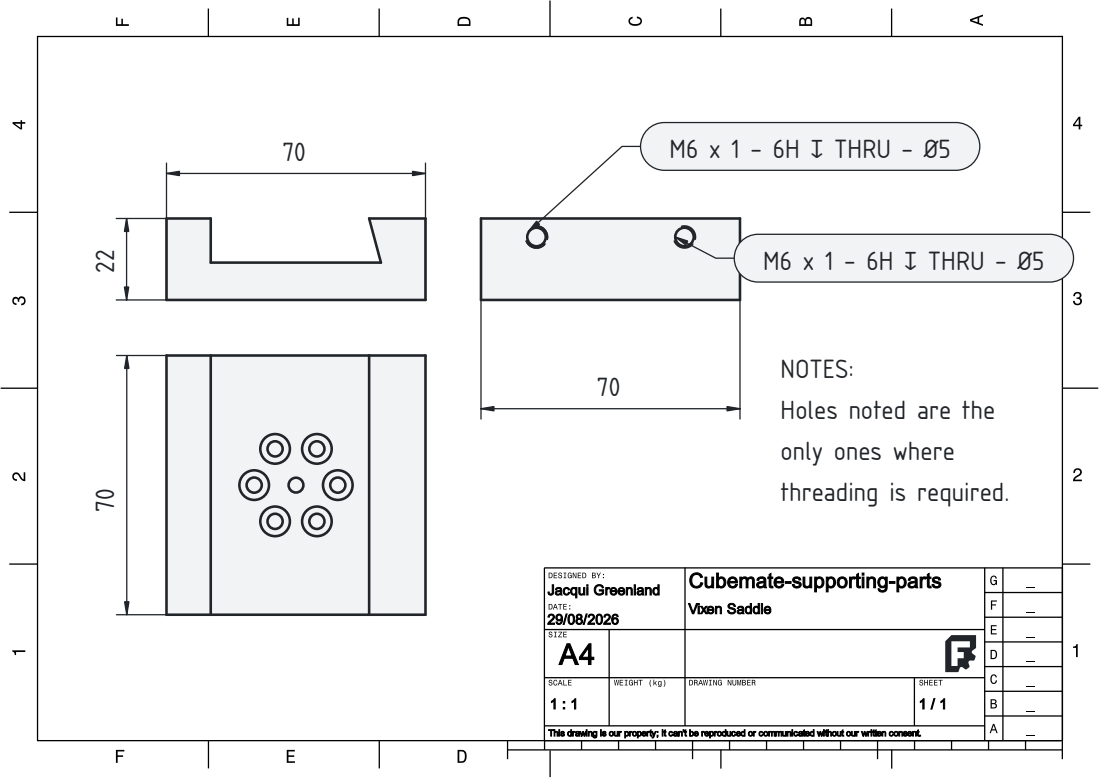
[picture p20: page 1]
S: Holes n; are th

ere threading is req

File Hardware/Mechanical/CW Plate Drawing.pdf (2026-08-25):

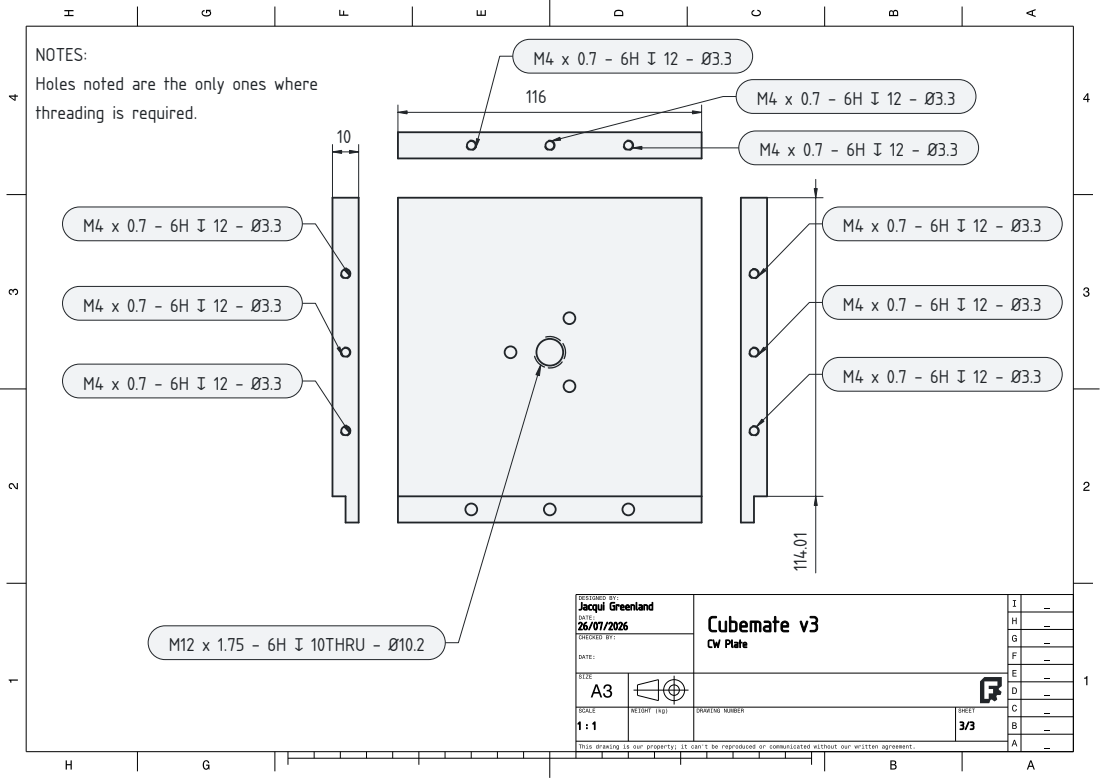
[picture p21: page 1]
M12 x 1.75 - 6H ↧ 10THRU - Ø10.2

Holes noted are the only ones where

threading is required.

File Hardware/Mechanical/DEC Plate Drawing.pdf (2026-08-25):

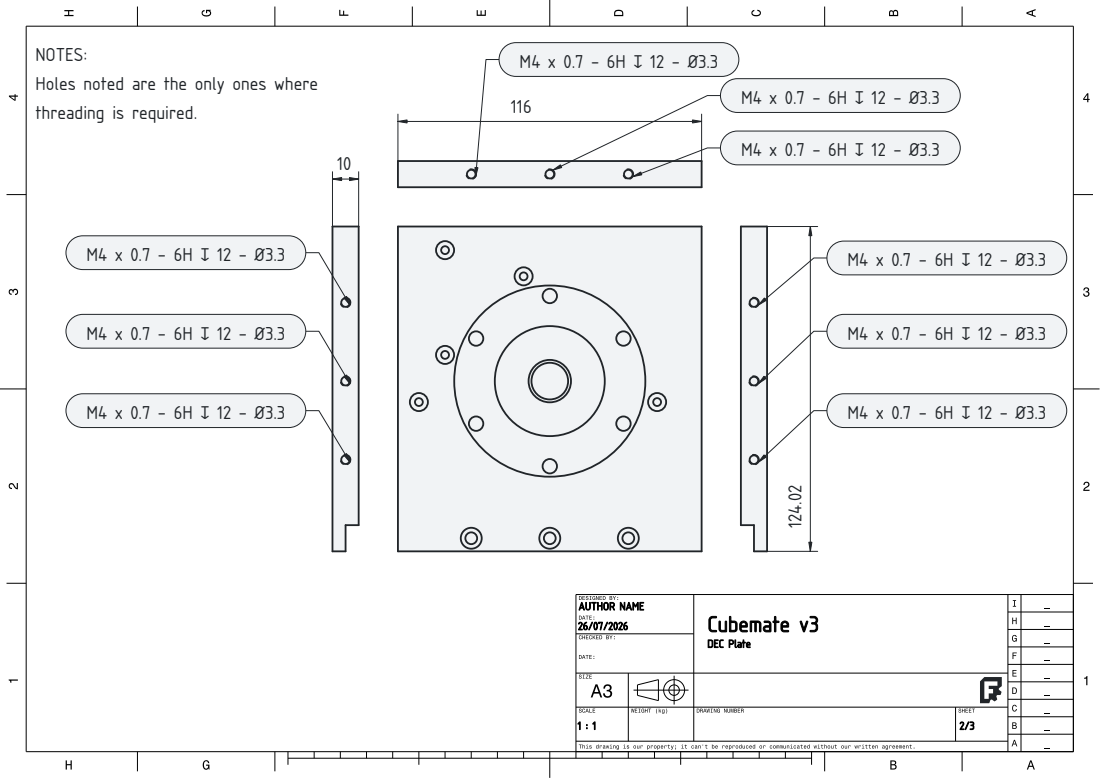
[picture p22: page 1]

Holes noted are the only ones where

threading is required.

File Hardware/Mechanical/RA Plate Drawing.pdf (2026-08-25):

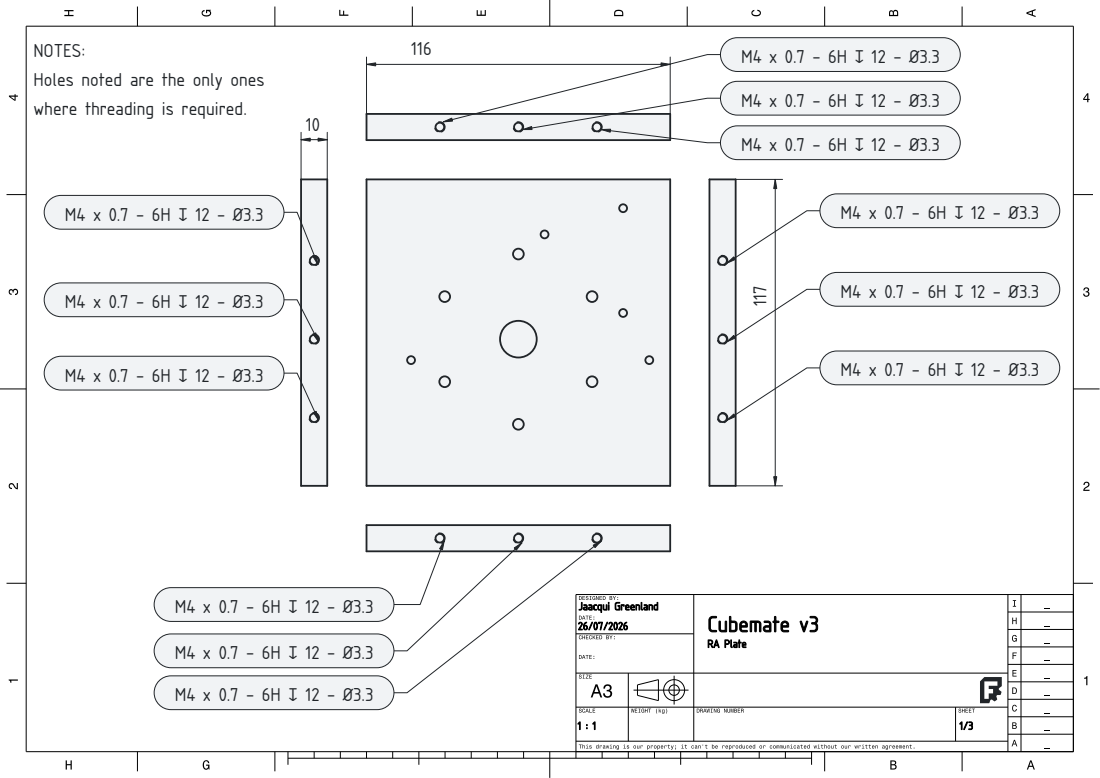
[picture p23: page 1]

Holes noted are the only ones

where threading is required.

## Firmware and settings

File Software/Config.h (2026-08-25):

/* ---------------------------------------------------------------------------------------------------------------------------------
 * Configuration for OnStepX
 *
 *          For more information on setting OnStep up see http://www.stellarjourney.com/index.php?r=site/equipment_onstep 
 *                      and join the OnStep Groups.io at https://groups.io/g/onstep
 * 
 *           *** Read the compiler warnings and errors, they are there to help guard against invalid configurations ***
 *
 * ---------------------------------------------------------------------------------------------------------------------------------
 * ADJUST THE FOLLOWING TO CONFIGURE YOUR CONTROLLER FEATURES ----------------------------------------------------------------------
 * <-Req'd = always must set, <-Often = usually must set, Option = optional, Adjust = adjust as req'd, Infreq = infrequently changed
*/
//      Parameter Name              Value   Default  Notes                                                                      Hint

// =================================================================================================================================
// CONTROLLER ======================================================================================================================
#define HOST_NAME                "OnStep-Cubemate" // nStep", Hostname for this device up to 16 chars.                                 Adjust

// PINMAP ------------------------------------------------- see https://onstep.groups.io/g/main/wiki/Configuration_Controller#PINMAP
#define PINMAP                        MaxESP4 //    OFF, Choose from: MiniPCB, MiniPCB2, MaxPCB4, MaxESP4, MaxSTM3, FYSETC_E4,   <-Req'd
                                          //         BTT_SKR_PRO, etc.  Other boards and more info. in ~/src/Constants.h

// SERIAL PORT COMMAND CHANNELS --------------------- see https://onstep.groups.io/g/main/wiki/Configuration_Controller#SERIAL_PORTS
#define SERIAL_A_BAUD_DEFAULT        115200 //   9600, n. Where n=9600,19200,57600,115200,230400,460800 (common baud rates.)    Infreq
#define SERIAL_B_BAUD_DEFAULT        OFF //   9600, n. Baud rate as above. See (src/pinmaps/) for Serial port assignments.   Infreq
#define SERIAL_B_ESP_FLASHING         OFF //    OFF, ON Upload ESP8266 WiFi firmware through SERIAL_B with :ESPFLASH# cmd.    Option
#define SERIAL_C_BAUD_DEFAULT         OFF //    OFF, n. Baud rate as above. See (src/pinmaps/) for Serial port assignments.   Infreq
#define SERIAL_D_BAUD_DEFAULT         OFF //    OFF, n. Baud rate as above. See (src/pinmaps/) for Serial port assignments.   Infreq
#define SERIAL_E_BAUD_DEFAULT         OFF //    OFF, n. Baud rate as above. See (src/pinmaps/) for Serial port assignments.   Infreq
#define SERIAL_RADIO                  WIFI_ACCESS_POINT //    OFF, Use BLUETOOTH or WIFI_ACCESS_POINT or WIFI_STATION (ESP32 only.)         Option

// STATUS --------------------------------------------- see https://onstep.groups.io/g/main/wiki/Configuration_Controller#STATUS_LED
#define STATUS_LED                    ON //    OFF, Steady illumination if no error, blinks w/error code otherwise.          Option

// RETICLE CONTROL ------------------------------- see https://onstep.groups.io/g/main/wiki/Configuration_Controller#RETICLE_CONTROL
#define RETICLE_LED_DEFAULT           OFF //    OFF, n. Where n=0..255 (0..100%) activates feature sets default brightness.   Option
#define RETICLE_LED_MEMORY            OFF //    OFF, ON Remember reticle brightness across power cycles.                      Option
#define RETICLE_LED_INVERT            OFF //    OFF, ON Inverts control for cases where 0V is max brightness.                 Option

// WEATHER SENSOR --------------------------------- see https://onstep.groups.io/g/main/wiki/Configuration_Controller#WEATHER_SENSOR
#define WEATHER                       OFF //    OFF, BME280 (I2C 0x77,) BME280_0x76, BME280_SPI (see pinmap for CS.)          Option
                                          //         BMP280 (I2C 0x77,) BMP280_0x76, BMP280_SPI (see pinmap for CS.)
                                          //         BME280 or BMP280 for temperature, pressure.  BME280 for humidity also.

// SIGNALING ------------------------------------------- see https://onstep.groups.io/g/main/wiki/Configuration_Controller#SIGNALING
#define STEP_WAVE_FORM             PULSE // SQUARE, PULSE Step signal wave form faster rates. SQUARE best signal integrity.  Adjust
                                          //         Applies to all axes.

// NON-VOLATILE MEMORY ---------------------------------------- see https://onstep.groups.io/g/main/wiki/Configuration_Controller#NV
#define NV_DRIVER              NV_DEFAULT // NV_DEF, Use platforms default non-volatile device to remember runtime settings.  Option
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

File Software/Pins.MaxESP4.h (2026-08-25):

// -------------------------------------------------------------------------------------------------
// Pin map for OnStep MaxESP4 (ESP32-S3-Zero)
#pragma once

#if defined(ESP32)

// Serial ports (see Pins.defaults.h for SERIAL_A)
// Serial0: RX Pin GPIO3, TX Pin GPIO1 (to USB serial adapter)
// Serial1: RX1 Pin GPIO10, TX1 Pin GPIO9 (on SPI Flash pins, must be moved to be used)
// Serial2: RX2 Pin GPIO16, TX2 Pin GPIO17

#if SERIAL_A_BAUD_DEFAULT != OFF
  #define SERIAL_A              Serial
  #define SERIAL_A_RX	12
  #define SERIAL_A_TX	13
#endif
#if SERIAL_B_BAUD_DEFAULT != OFF
#endif

// Use the following settings for any TMC UART driver (TMC2209) that may be present
#if defined(STEP_DIR_TMC_UART_PRESENT) || defined(SERVO_TMC2209_PRESENT)
  #define SERIAL_TMC_HARDWARE_UART
  #define SERIAL_TMC            Serial1          // Use a single hardware serial port to up to four drivers
  #define SERIAL_TMC_BAUD       460800          // Baud rate
  #define SERIAL_TMC_RX         5               // Recieving data
  #define SERIAL_TMC_TX         6                // Transmit data
  #define SERIAL_TMC_ADDRESS_MAP(x) ((x==4)?2 : x) // Axis1(0) is 0, Axis2(1) is 1, Axis3(2) is 2, Axis4(3) is 3, Axis5(4) is 2
#endif



// Specify the ESP32 I2C pins
#define I2C_SDA_PIN             25
#define I2C_SCL_PIN             26

// The multi-purpose pins (Aux3..Aux8 can be analog pwm/dac if supported)
#define AUX2_PIN                17               // M3 pin TMC UART RX
#define AUX3_PIN                43              // Home SW for Axis1
#define AUX4_PIN                44               // Home SW for Axis2
#define AUX5_PIN                OFF               // TX0 main USB, etc.
#define AUX6_PIN                OFF                // RX0 main USB, etc.
#define AUX7_PIN                OFF               // Limit SW, PPS, etc.
#define AUX8_PIN                10               // 1-Wire, Status LED, Reticle LED, Tone, etc.

// Misc. pins
#ifndef ONE_WIRE_PIN
  #define ONE_WIRE_PIN          AUX8_PIN         // Default Pin for OneWire bus
#endif

// The PEC index sense is a logic level input, resets the PEC index on rising edge then waits for 60 seconds before allowing another reset
#ifndef PEC_SENSE_PIN
  #define PEC_SENSE_PIN         11               // [input only 36] PEC Sense, analog (A0) or digital (GPIO36)
#endif

// The status LED w/ 4.7k resistor in series to limit the current to the LED
#ifdef STATUS_LED_ON_STATE
  #undef STATUS_LED_ON_STATE
#endif
#define STATUS_LED_ON_STATE HIGH
#ifndef STATUS_LED_PIN
  #define STATUS_LED_PIN        7               // Default LED Anode (+)
#endif
#ifdef MOUNT_LED_ON_STATE
  #undef MOUNT_LED_ON_STATE
#endif
#define MOUNT_LED_ON_STATE      HIGH
#define MOUNT_LED_PIN           STATUS_LED_PIN   // Default LED Anode (+)
#ifndef RETICLE_LED_PIN
  #define RETICLE_LED_PIN       AUX8_PIN         // Default LED Cathode (-)
#endif

// For a piezo buzzer
#ifndef STATUS_BUZZER_PIN
  #define STATUS_BUZZER_PIN     OFF               // [must be low at boot 12] Tone
#endif

// The PPS pin is a 3.3V logic input, OnStep measures time between rising edges and adjusts the internal sidereal clock frequency
#ifndef PPS_SENSE_PIN
  #define PPS_SENSE_PIN         AUX7_PIN         // PPS time source, GPS for example
#endif

// The limit switch sense is a logic level input normally pull high (2k resistor,) shorted to ground it stops gotos/tracking
#ifndef LIMIT_SENSE_PIN
  #define LIMIT_SENSE_PIN       AUX7_PIN
#endif

#define SHARED_DIRECTION_PINS                    // Hint that the direction pins are shared
#define SHARED_ENABLE_PIN       45                // Hint that the enable pins are shared

// Axis1 RA/Azm step/dir driver
#define AXIS1_ENABLE_PIN        SHARED           // Enable pin control
#define AXIS1_M0_PIN            OFF              // hardwired for TMC UART address 0
#define AXIS1_M1_PIN            OFF              // hardwired for TMC UART address 0
#define AXIS1_M2_PIN            OFF              // UART TX
#define AXIS1_M3_PIN            OFF              // UART RX
#define AXIS1_STEP_PIN          4
#define AXIS1_DIR_PIN           3                // [must be high at boot 0]
#ifndef AXIS1_SENSE_HOME_PIN
  #define AXIS1_SENSE_HOME_PIN  AUX3_PIN
#endif

// Axis2 Dec/Alt step/dir driver
#define AXIS2_ENABLE_PIN        SHARED
#define AXIS2_M0_PIN            OFF              // hardwired for TMC UART address 1
#define AXIS2_M1_PIN            ON              // hardwired for TMC UART address 1
#define AXIS2_M2_PIN            OFF              // N/C
#define AXIS2_M3_PIN            OFF              // UART RX
#define AXIS2_STEP_PIN          2
#define AXIS2_DIR_PIN           1
#ifndef AXIS2_SENSE_HOME_PIN
  #define AXIS2_SENSE_HOME_PIN  AUX4_PIN
#endif
#ifndef AXIS2_ENCODER_B_PIN
  #define AXIS2_ENCODER_B_PIN   AUX2_PIN
#endif
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

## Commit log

2026-08-25 Rename vixen saddle-Body.step to vixen saddle.step
    [vixen saddle.step]
2026-08-25 Rename vixen saddle.step to Cubemate - Vixen Saddle.step
    [Cubemate - Vixen Saddle.step]
2026-08-25 Rename Cubemate - Vixen Saddle.step to Cubemate-Vixen Saddle.step
    [Cubemate-Vixen Saddle.step]
2026-08-25 Rename Cubemate-side plate 1.step to Cubemate-Side Plate 1.step
    [Cubemate-Side Plate 1.step]
2026-08-25 Create PCB Bill of Materials.md
2026-08-25 Rename PCB Bill of Materials to PCB Bill of Materials.md
2026-08-25 Update PCB Bill of Materials.md
